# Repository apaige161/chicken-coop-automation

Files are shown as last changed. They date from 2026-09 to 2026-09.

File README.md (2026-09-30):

# Automated 50-Bird Chicken Coop

This is a complete, buildable design for a **10 × 20 ft coop for 50 free-ranging hens**:
the structure, run and paddocks, water and power, plus an **ESP32 + ESPHome controller**
that integrates with **Home Assistant**. Every subsystem starts **low-tech**, and the
automation is an upgrade you can add later.

> ⚠️ **Safety and code.** This project includes **120 V mains wiring outdoors** and a
> **load-bearing structure**. The plans are detailed, but they are **not** a substitute for
> a **licensed electrician** (all 120 V work, GFCI protection, inspection) or for your
> **local building department** (permit, setbacks, snow/wind loads). The controller PCB
> itself carries only 12 V DC.

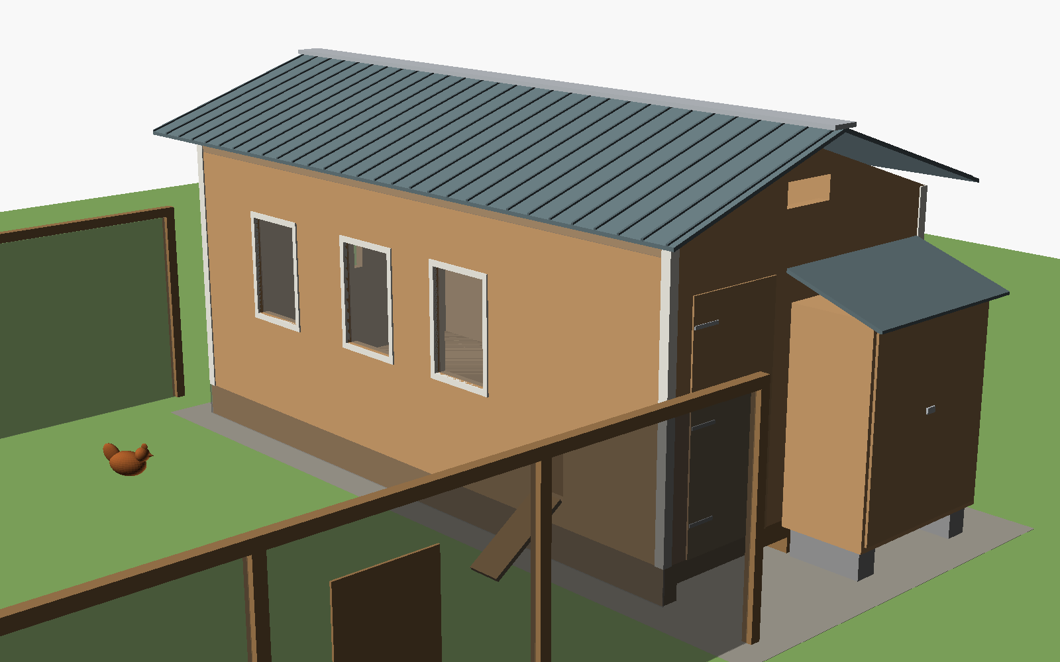
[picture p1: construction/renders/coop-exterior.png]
coop exterior


| Feed & water station (filled from outside) | Inside: roosts, nest openings, trough, drinkers |
|---|---|
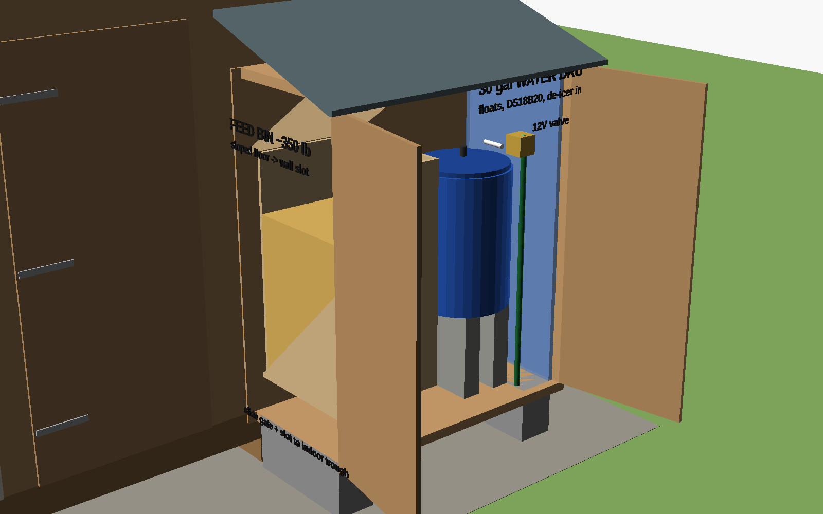
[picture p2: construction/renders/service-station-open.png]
service station
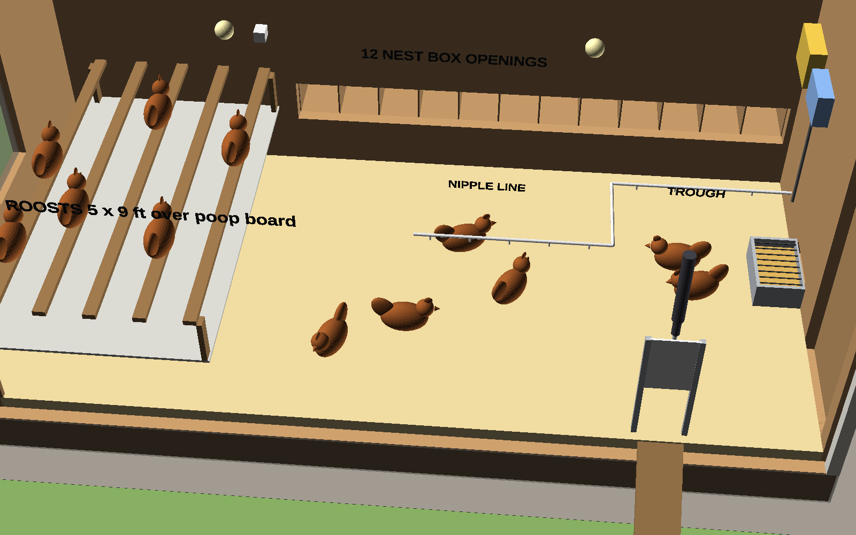
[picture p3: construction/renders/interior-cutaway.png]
interior
|  |  |
| **Nest bay (eggs collected from outside)** | **Controller PCB** |
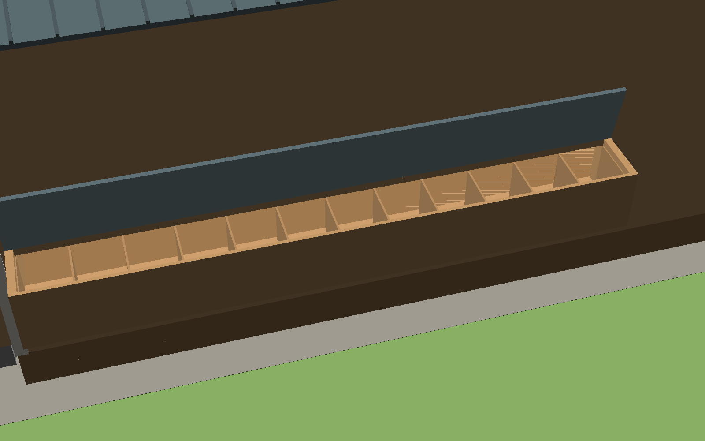
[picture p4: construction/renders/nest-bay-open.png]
nest bay
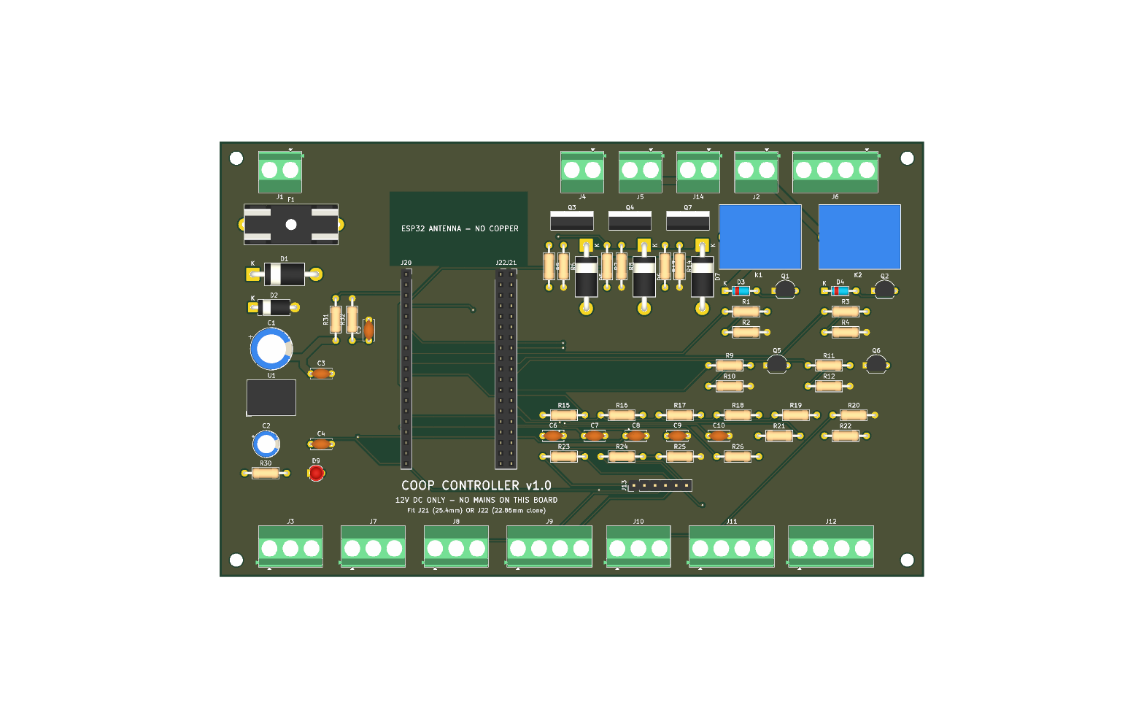
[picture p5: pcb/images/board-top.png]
pcb
|  |  |

The renders are illustrative OpenSCAD models (`construction/model/`). Dimensions come from
the build plan and drawings.

**Feed, water and eggs are all serviced from outside the coop.** An exterior service station
on the east wall holds a ~350 lb gravity feed bin (it feeds an indoor trough through a wall
slot) and the 30 gal water drum (piped through the wall to the nipple line). The nest bay
lid opens from outside.

## What's here

| Folder | Contents | Checked by |
|---|---|---|
| [`PROJECT_SPEC.md`](PROJECT_SPEC.md) | Architecture, sizing, tiers, power design, **GPIO map** | consistency check |
| [`hardware/pinmap.yaml`](hardware/pinmap.yaml) | Single source of truth for GPIOs and terminals | consistency check |
| [`firmware/`](firmware/) | ESPHome configs: controller + optional ESP32-CAM | `esphome config` + full compile |
| [`pcb/`](pcb/) | KiCad 10 schematic + 2-layer board, generated from `design.py`, autorouted, Gerbers ready to order | ERC 0 · DRC 0 errors · 0 unrouted · schematic parity |
| [`3d-printing/`](3d-printing/) | 8 OpenSCAD designs → 15 STLs (sensor housings, camera, brackets, PCB plate, optional auger funnel) | `render.sh` |
| [`construction/`](construction/) | Build plan + cut list, exterior feed/water station, wiring, plumbing, run and range, 5 diagrams, 6 renders | diagrams regenerate from `pinmap.yaml` |
| [`docs/`](docs/) | [Priced parts list](docs/parts-list.md), [cost-saving measures](docs/cost-savings.md), [Home Assistant setup](docs/home-assistant.md), HA automations + dashboard | `gen_parts_list.py --check`, yamllint |
| [`tools/`](tools/) | `check_consistency.py`, `gen_parts_list.py` | CI |

## Cost (2026 estimates, see [parts list](docs/parts-list.md))

| Tier | Approx. |
|---|---:|
| Tier 1: coop, run, electric-netting paddocks, exterior feed/water station, power to the coop | ~$9.6k |
| Tier 2: full automation (controller, PCB, door actuator, water fill, sensors) | ~$0.65k |
| Optional: camera, BLE sensors, battery backup, metered auger | ~$0.2k |

The cost-saving measures in [`docs/cost-savings.md`](docs/cost-savings.md) are already applied
(about −$950 net, *after* adding the exterior station). The biggest remaining levers are a
local lumber-package quote (±30 % on lumber) and how much of the ~$900 electrician estimate
you can reduce, for example by digging the trench yourself.

## Tiers at a glance

| Subsystem | Tier 1 (works with no electronics) | Tier 2 (controller) |
|---|---|---|
| Pop door | Guillotine door + rope/pulley | 12 V actuator, on-device sunrise/civil-dusk schedule, reed confirmation, HA alerts |
| Water | 30 gal drum in the exterior station, piped through the wall to nipples. Hose-fill from outside, or a mechanical float valve | Fail-closed solenoid, dual floats, timeout lockout, freeze-aware |
| Winter water | Insulated station + heated waterer on the GFCI outlet | DS18B20-controlled de-icer / heat cable via relay |
| Feed | ~350 lb gravity bin in the exterior station → wall slot → indoor trough, filled from outside | Ultrasonic bin level + low-feed alert. Optional metered auger |
| Light | Switch | Morning supplement to 14 h day length |
| Ventilation | Soffit/ridge/gable/windows (≥ 20 sq ft) | 12 V fan on temp/RH |
| Security | Hardware cloth, buried apron, 2-step latches, electric netting | PIR night-motion alerts, door-open-after-dark alert, optional camera |

## Build order

1. **Plan and permit.** Read `PROJECT_SPEC.md` and `construction/coop-build-plan.md`. Check
   local code, snow/wind loads and setbacks. Get a lumber quote from the cut list.
2. **Site, foundation, floor, walls, roof** (`coop-build-plan.md` §2 steps 1–9).
3. **Predator proofing and openings.** Hardware cloth everywhere, apron, doors, windows,
   nest bay, roosts.
4. **Run and paddocks** (`run-and-fencing.md`).
5. **Exterior feed & water station** (`coop-build-plan.md` §7): gravity feed bin + indoor
   trough, drum + drinker line through the wall, supply chain (`plumbing.md`).
   **Birds can move in now.** Keep them in the run for 1–2 weeks so they learn the coop is home.
6. **Power** (`wiring.md`). The electrician installs the feeder, mains box, lights and GFCI
   receptacle.
7. **Controller:** order the PCB (`pcb/fab/coop-controller-gerbers.zip`), print the parts
   (`3d-printing/stl/`), buy the Tier 2 parts, assemble and bring up the board
   (`pcb/README.md`), flash the firmware and adopt it in HA (`docs/home-assistant.md`).
8. **Commission one subsystem at a time:** door (adjust the reeds, watch a dusk close),
   then water fill, de-icer, feed-level sensor, lights, fan. Import the HA automations and
   dashboard.
9. **Optional:** camera, BLE thermometers, battery backup.

## Verify everything (what CI runs)

```bash
python tools/check_consistency.py      # pin map ↔ firmware ↔ PCB ↔ spec ↔ HA entity IDs ↔ schematic
python tools/gen_parts_list.py --check  # parts list totals are current
python construction/gen_diagrams.py     # diagrams regenerate
esphome config firmware/coop-controller.yaml
bash 3d-printing/render.sh
bash pcb/build.sh                       # needs KiCad 10 + Java + Freerouting: ERC/DRC/fab outputs
```

## Before building: check these by hand

These are the things software checks can't prove:

- [ ] **PCB:** open it in KiCad and review the autorouted layout. Confirm the SRD relay
      pinout on your parts, and your ESP32 board's row spacing (fit J21 for 25.4 mm or
      J22 for 22.86 mm). See `pcb/README.md`.
- [ ] **Firmware:** set your latitude/longitude/timezone and feeding times, and your BLE
      thermometer's MAC (or remove `packages/ble.yaml`).
- [ ] **3D parts:** measure your specific sensors and PVC and adjust the parameters in the `.scad` headers.
- [ ] **Structure:** check rafter size against your local snow load, and pull a permit if needed.
- [ ] **Electrical:** a licensed electrician does all 120 V work, with GFCI on everything.

## Design decisions

- **ESPHome** rather than Arduino/ESP-IDF: it's local-first, integrates natively with
  HA, and each entity is a few lines of YAML, which keeps the upgrade path cheap.
- **KiCad** rather than Eagle: it's free, it's scriptable (the board is generated and
  verified from `pcb/design.py`), and it outputs standard Gerbers for any fab.
- **Mains stays off the PCB.** The relay modules (or SSRs) and PSU sit in a separate
  electrician-installed box. The PCB only drives their 12 V coils/inputs.
- **Service from outside.** Feed, water and egg collection never require entering the coop,
  which cuts labour, spills and biosecurity risk.

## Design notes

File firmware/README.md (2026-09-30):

# Firmware (ESPHome)

| File | Device |
|---|---|
| `coop-controller.yaml` | Main controller: ESP32-DevKitC-32E on the Coop Controller PCB |
| `packages/base.yaml` | WiFi/AP fallback, API (encrypted), OTA, web UI, SNTP/HA time, sun, status LED, 12 V monitor |
| `packages/door.yaml` | Pop door: relay H-bridge, reed end stops, sun-elevation schedule with a lux fallback, fault alerts |
| `packages/water.yaml` | Float-controlled fill with timeout lockout + valve watchdog, DS18B20, de-icer thermostat |
| `packages/feeder.yaml` | Feed-bin level (JSN-SR04T) + low-feed alert. Optional metered auger (schedule off by default) with door/auger power interlock |
| `packages/lighting_fan.yaml` | Morning light supplement to the target day length, temp/RH exhaust fan |
| `packages/environment.yaml` | BME280 + BH1750 on I2C |
| `packages/security.yaml` | PIR + "night motion" |
| `packages/ble.yaml` | BLE tracker + HA Bluetooth proxy + pvvx thermometer example |
| `coop-camera.yaml` | Optional AI-Thinker ESP32-CAM |

GPIO numbers **must** match `hardware/pinmap.yaml`. Each `GPIOxx` line carries a
`# SIGNAL_NAME` comment, which `tools/check_consistency.py` verifies.

## Design rules

- **Local first.** Nothing the birds depend on needs HA or internet. `reboot_timeout: 0s`
  on the API and WiFi means the controller never reboots just because HA or WiFi is gone.
- **Fail safe.** All outputs are `ALWAYS_OFF` at boot, with gate pull-downs on the PCB.
  The door relays interlock in software, and the relay topology makes shoot-through
  impossible anyway. The valve closes on timeout and has its own watchdog. The optional auger
  has a 150 s cap. The float wiring convention makes a broken wire read as "don't fill".
- **Manual overrides stick** until the next scheduled transition, because the door and
  light schedulers only act on *changes* in the desired state.
- **Everything tunable is a `number`/`switch` entity** (restored across reboots), so
  thresholds change from HA or the web UI without reflashing.

## Build / flash

```bash
pip install esphome
cp secrets.example.yaml secrets.yaml      # then edit it
esphome config coop-controller.yaml       # validate
esphome run coop-controller.yaml          # compile + flash (USB first time, then OTA)
```

Verified with ESPHome 2026.9.0 (esp-idf 5.5.5): the controller uses 61 % RAM / 75 % flash,
the camera 32 % RAM / 54 % flash.

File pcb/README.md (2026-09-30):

# Coop Controller PCB (KiCad)

This is a 2-layer, all through-hole carrier board for an **ESP32-DevKitC-32E**. It has 12 V
input protection, a 5 V regulator, a 2-relay H-bridge for the pop-door actuator, five
low-side MOSFET outputs, conditioned sensor inputs, and screw terminals for all field
wiring. **It carries 12 V DC only.** The 120 V relays/SSRs and PSU live in a separate mains
enclosure (see `construction/wiring.md`).

top

| | |
|---|---|
| Size | 170 × 105 mm, 4× M3 holes 4 mm from each corner |
| Layers | 2 (1 oz), GND pour both sides, solid pad connections |
| Tracks | Signal 0.25 mm / 0.2 mm clearance. Power nets (`+12V`, `GND`, `M±`, `VALVE-`, `FEEDER-`, `FAN-`, `VIN_*`) 1.5 mm |
| Parts | 75 THT parts, 38 BOM lines (`fab/bom.csv`) |
| Checks | ERC 0 violations. DRC 0 errors, 0 unconnected, 0 schematic-parity issues |

## Files

| File | What it is |
|---|---|
| `design.py` | **The source.** Every part, footprint, pin→net and board position |
| `gen_schematic.py` | Writes `coop-controller.kicad_sch` from `design.py` (labels on every pin) |
| `gen_pcb.py` | Writes `coop-controller.kicad_pcb` + `.kicad_pro` (placement, net classes, outline, keep-out, pours) |
| `route.py` | Autoroutes with Freerouting (retries until 100% routed) and fills the pours |
| `gen_bom.py` | Grouped BOM → `fab/bom.csv` |
| `build.sh` | Runs everything above, plus ERC/DRC and fab exports |
| `fab/coop-controller-gerbers.zip` | **Upload this to the fab** (Gerbers + Excellon drill) |
| `fab/coop-controller-schematic.pdf` | Printable schematic |

The schematic is generated, so it's a netlist-style sheet grouped by function, with net
labels instead of drawn wires. That's deliberate: `tools/check_consistency.py` can prove it
matches `design.py` and the firmware pin map. To change the circuit, edit `design.py` and
run `bash build.sh`. Don't hand-edit the generated files, or the next build will overwrite
your changes.

## Before you order: manual checks

The layout is autorouted and passes DRC, but nobody has looked at it in the KiCad GUI yet.
Open `coop-controller.kicad_pcb` in KiCad and check:

1. **Relay pinout.** `design.py` assumes SRD pins 1 = COM, 2/5 = coil, 3 = NO, 4 = NC
   (KiCad's `SANYOU_SRD_Form_C` symbol). Confirm this on your actual relays with a
   meter before soldering.
2. **ESP32 fit.** Measure your dev board. Official Espressif DevKitC rows are 25.4 mm apart
   (fit **J21**). Many clones are 22.86 mm (fit **J22** instead). Fit only one of the two.
   Make sure the USB connector sits at the bottom (J20/J21 pin 19 end) and the antenna
   overhangs the "NO COPPER" keep-out.
3. **Terminal-block orientation.** Wire entries should face the board edges.
4. **Track routing.** Look over the Freerouting result: power-track widths, sensible
   paths, no long GND detours.
5. Run **Inspect → Design Rules Checker** once in the GUI.

## Ordering (JLCPCB / PCBWay / OSH Park)

1. Upload `fab/coop-controller-gerbers.zip`.
2. Settings: 2 layers, 1.6 mm FR-4, 1 oz copper, HASL (lead-free) or ENIG, any mask colour.
   Minimum track/space on this board is 0.25/0.2 mm, which every hobby fab handles.
3. Expect roughly **$15–30 for 5 boards** plus shipping, since it's over 100×100 mm.
4. The parts are all through-hole and commonly stocked, so hand-solder them from
   `fab/bom.csv` (Digi-Key/Mouser/LCSC). Prices are in `docs/parts-list.md`.

## Assembly order

Solder low to high: resistors, diodes, small caps, TO-92 transistors, then the pin
header/sockets (use a spare dev board to hold the sockets straight), TO-220 MOSFETs,
electrolytics, fuse holder, regulator, relays and terminal blocks last.

**Bring-up before plugging in the ESP32:**
1. Apply 12 V from a current-limited bench supply (limit to about 200 mA). Check that
   D9 lights, 5 V is on J10 pin 1, and nothing gets warm.
2. Check reverse polarity: swap the leads briefly. Nothing should happen, because D1
   blocks it.
3. Fit the ESP32, flash `firmware/coop-controller.yaml` over USB, then test each output
   from the ESPHome web UI with nothing connected. Listen for the relay clicks and check
   that the MOSFET drains pull low.

## Circuit notes

- **Door H-bridge:** K1/K2 SPDT. NC→GND, NO→+12 V, COM→motor lead. Both relays off (or
  both on) shorts the motor to itself, which brakes it. Shoot-through is impossible by
  construction. See the truth table in `PROJECT_SPEC.md`.
- **Low-side outputs:** IRLZ44N (or IRLB8721) logic-level FETs with 100 Ω gate and 100 kΩ
  pull-down resistors, so outputs stay OFF while the ESP32 boots. 1N5822 flyback diodes
  protect against the valve/motor/fan inductance. 2N7000 FETs drive the relay coils (1N4148
  flyback) and the J6 outputs for the mains-box relay-module coils (~20 mA; use modules with
  a built-in suppression diode) or SSR inputs (~10 mA). J5 (FEEDER) is only used by the
  optional metered auger.
- **Inputs:** 10 kΩ pull-ups to 3.3 V plus a 100 nF cap on every long-wire input. The PIR
  has a 10 kΩ pull-down. The JSN-SR04T 5 V echo goes through a 1 k/2 k divider.
- **VIN sense:** 100 k/22 k divider into GPIO36. The firmware multiplies by 5.545.
- **Protection:** 5 A slow-blow fuse, SB560 series Schottky (reverse polarity), and a
  P6KE15CA TVS across +12 V.

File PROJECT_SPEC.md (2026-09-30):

# Project Spec: Automated 50-Bird Chicken Coop

This is the shared architecture document. Firmware, PCB, wiring diagrams, 3D parts and
construction plans all follow it. If you change it, change it here first, then update
`hardware/pinmap.yaml` and run `python tools/check_consistency.py`.

> **SAFETY — READ FIRST.** This project includes 120 V AC mains wiring outdoors and a
> load-bearing structure for 50 birds plus snow and wind loads. These plans are thorough,
> but they do **not** replace a licensed electrician or a local building/code review.
> All outdoor 120 V circuits must be **GFCI protected** and installed to local code
> (NEC in the US). Have the electrical work inspected and the structure checked against
> your local snow/wind loads before you build.

## 1. Design philosophy

Every subsystem has a **Tier 1 (low-tech)** baseline that works with no electronics at all,
and a **Tier 2 (automated)** upgrade that the controller adds on top. The flock stays safe
if the controller, WiFi or Home Assistant fails:

- The pop door runs from **local sunrise/sunset logic on the ESP32**. It does not need Home
  Assistant or internet, and a physical button on the enclosure works without WiFi.
- A mechanical float valve or a manual fill still waters the birds if the solenoid fails.
- Feed and water are gravity-fed from an **exterior service station**, so a failed controller
  never stops the birds eating or drinking.

## 2. Site assumptions

| Item | Value |
|---|---|
| Flock | 50 standard-size laying hens, free-ranging most of the day |
| Shade | Partial. Put the long glazed wall facing south (north hemisphere) for winter sun, with deciduous shade in summer if you can |
| Power | 120 V outlet nearby. Run a dedicated GFCI-protected 20 A circuit to the coop |
| Water | Hose spigot nearby. Use a vacuum breaker, 25 psi regulator and a drinking-water-safe hose |

## 3. Coop sizing (50 birds)

| Parameter | Rule of thumb | Design value |
|---|---|---|
| Indoor floor area | 4 sq ft/bird | **10 ft × 20 ft = 200 sq ft** |
| Nest boxes | 1 per 4–5 hens | **12 boxes** in one row (12"W × 12"H × 14"D), exterior bay on the north wall, floor 20" up, so all boxes sit below the 36–40" roosts |
| Roost length | 8–10 in/bird | **5 bars × 9 ft = 45 ft** (10.8 in/bird), spanning the 9'-5" interior width |
| Ventilation | ~1 sq ft per 10 sq ft floor | **≥20 sq ft** of screened soffit, gable and window openings |
| Pop door | 1 per ~50 birds | **12" W × 16" H**, vertical guillotine, 12 V 18"-stroke actuator |
| Secure run (bad-weather days) | ~10 sq ft/bird | **20 ft × 25 ft = 500 sq ft**, roofed or netted |
| Feed | ~0.25 lb/bird/day | **~12.5 lb/day** (~90 lb/week) |
| Water | ~0.12–0.25 gal/bird/day | **6–12 gal/day**. A 30 gal reservoir lasts 2.5–5 days |
| Feed + water access | Fill without entering the coop | **Exterior service station** on the east wall (5 ft × 30 in × 6 ft): ~350 lb gravity feed bin + 30 gal drum, both filled from outside |

## 4. System architecture

```
                      +-------------------- Home Assistant ---------------------+
                      |  dashboards, overrides, notifications, history          |
                      +--------------------------+------------------------------+
                                                 | ESPHome native API (WiFi, encrypted)
          BLE (passive)                          |
 [BLE thermometer(s)] ~~~~~~~~~~~~~~>  +---------+-----------+      optional     +-------------+
 (nest box / brooder)                  |  Coop Controller    |  <--- WiFi ---->  | ESP32-CAM   |
                                       |  ESP32-DevKitC-32E  |                   | (camera)    |
                                       |  on Coop Ctrl PCB   |                   +-------------+
                                       +--+--+--+--+--+--+--+
     12 V DC loads:  door actuator (2-relay H-bridge), water solenoid, 12 V fan, (optional feed auger)
     Low-voltage in: door reeds, water floats, DS18B20, BME280, BH1750, PIR, ultrasonic, button
     Relay/SSR out:  relay 1 -> 120 V coop lights, relay 2 -> 120 V de-icer (mains stays OFF the PCB)
```

- **Firmware:** ESPHome (YAML). It is local-first and integrates natively with Home Assistant.
  The coop logic (door schedule, water fill, freeze protection, lighting, feeding) runs on
  the device. Home Assistant supervises and can override.
- **BLE:** The controller runs `esp32_ble_tracker` passively to read BLE thermometers such
  as the Xiaomi LYWSD03MMC with pvvx firmware in the nest boxes or brooder. It also works
  as a Home Assistant **Bluetooth proxy**, so more BLE sensors can be added later without
  new hardware.
- **Camera (optional):** A separate ESP32-CAM node running ESPHome, or any RTSP/ONVIF
  camera added to Home Assistant directly.

## 5. Power architecture

```
House panel --[20 A GFCI breaker]-- UF-B 12/2 (buried per code) --> Coop weatherproof mains box
   Mains box (NEMA 4X / IP65), DIN rail:
     - 2-pole disconnect / 20 A breaker
     - GFCI receptacle (if not GFCI at panel)
     - Mean Well HDR-100-12N (12 V 7.5 A DIN PSU) ---> 12 V to controller box
     - Relay 1: DIN relay module, 12 VDC coil, 6 A (or SSR) -> coop LED lights
     - Relay 2: same                                       -> water de-icer / heat cable (<= 500 W)
   Optional: 12 V 7 Ah SLA battery + float charger for door backup during power cuts
```

- The **controller PCB carries 12 V DC and below only.** It switches the relay coils (or SSR
  inputs) on the low side. The relays, PSU and all 120 V conductors live in a separate
  mains enclosure. Use relay modules with a built-in suppression diode.
- 12 V input: 5 A fuse → reverse-polarity Schottky → TVS → loads. 5 V comes from an
  onboard switching regulator (7805-footprint module). The ESP32 dev board takes 5 V on
  its `5V` pin and makes 3.3 V itself.

## 6. Controller GPIO map (single source of truth: `hardware/pinmap.yaml`)

Board: **ESP32-DevKitC-32E** (38-pin, ESP32-WROOM-32E). Strapping pins (0, 2, 5, 12, 15)
are avoided or used only in boot-safe ways. GPIO 34/35/36/39 are input-only and have no
internal pull-ups, so the PCB provides external 10 kΩ pull-ups.

| GPIO | Signal | Dir | Connector | Notes |
|---|---|---|---|---|
| 21 | I2C_SDA | I/O | J9 | BME280 (0x76), BH1750 (0x23). 4.7 kΩ pull-ups on PCB |
| 22 | I2C_SCL | O | J9 | |
| 4 | ONEWIRE | I/O | J8 | DS18B20 in the water reservoir. 4.7 kΩ pull-up |
| 25 | DOOR_OPEN_RLY | O | J2 (via K1) | Relay K1: actuator M+ to +12 V (extend = open) |
| 26 | DOOR_CLOSE_RLY | O | J2 (via K2) | Relay K2: actuator M− to +12 V (retract = close) |
| 32 | DOOR_CLOSED_SW | I | J3 | Reed switch to GND, pulled up |
| 33 | DOOR_OPEN_SW | I | J3 | Reed switch to GND, pulled up |
| 27 | VALVE_DRV | O | J4 | Low-side MOSFET, 12 V NC solenoid valve |
| 13 | FEEDER_DRV | O | J5 | Low-side MOSFET, optional 12 V metered-auger motor |
| 14 | FAN_DRV | O | J14 | Low-side MOSFET, 12 V exhaust fan (may blip at boot; harmless) |
| 16 | LIGHT_SSR | O | J6 | Low-side MOSFET → relay 1 coil / SSR1 input (120 V lights) |
| 17 | HEAT_SSR | O | J6 | Low-side MOSFET → relay 2 coil / SSR2 input (120 V de-icer) |
| 34 | WATER_LOW | I | J7 | Float switch to GND, ext. 10 kΩ pull-up, RC filter |
| 35 | WATER_HIGH | I | J7 | Float switch to GND, ext. 10 kΩ pull-up, RC filter |
| 39 | PIR | I | J10 | HC-SR501 output (3.3 V logic), 10 kΩ pull-down |
| 18 | US_TRIG | O | J11 | JSN-SR04T feed-bin level ultrasonic trigger |
| 19 | US_ECHO | I | J11 | 5 V echo through a 1 kΩ/2 kΩ divider |
| 23 | DOOR_BTN | I | J12 | Panel push button to GND (manual door toggle) |
| 2 | STATUS_LED | O | J12 | Onboard LED + panel LED (330 Ω) |
| 36 | VIN_SENSE | ADC | — | 12 V rail through 100 kΩ/22 kΩ divider (battery/PSU health) |
| 5 | SPARE_IO5 | I/O | J13 | Expansion header. Strapping pin: do not pull low at boot |

**Door H-bridge truth table** (K1/K2 are SPDT; NC→GND, NO→+12 V, COM→motor lead):

| K1 | K2 | M+ | M− | Result |
|---|---|---|---|---|
| off | off | GND | GND | Stopped (dynamic brake) |
| on | off | +12 V | GND | Extend → **door opens** |
| off | on | GND | +12 V | Retract → **door closes** |
| on | on | +12 V | +12 V | Stopped (no shoot-through possible) |

The firmware still interlocks K1/K2. The actuator's built-in limit switches are the
primary end stop. The reed switches and a 30 s runtime timeout are secondary.

## 7. Subsystems

| Subsystem | Tier 1 (low-tech) | Tier 2 (automated) |
|---|---|---|
| Pop door | Manual guillotine door + rope/pulley and latch | 12 V linear actuator, sunrise/sunset + lux logic on-device, reed confirmation, HA alert if not closed 30 min after sunset |
| Feeder | ~350 lb gravity bin in the exterior station, feeding an indoor trough through a wall slot, filled from outside | Ultrasonic feed-level sensor + low-feed alert. Optional metered auger on J5 for rationing |
| Water | 30 gal drum in the exterior station, piped through the wall to nipples/cups, hose-filled from outside | 12 V NC solenoid from spigot, low/high float fill control with max-runtime and leak lockout |
| Freeze protection | Insulated station + heated bucket by hand | DS18B20 water temp → relay 2 de-icer/heat cable, HA freeze alerts |
| Lighting | Manual switch | Relay 1 adds morning light to keep 14 h of daylight in winter |
| Ventilation | Screened soffit/gable/window openings | 12 V exhaust fan on temperature/humidity thresholds |
| Environment | Min/max thermometer | BME280 (T/RH/P), BH1750 lux, BLE thermometers, HA history |
| Security | Hardware cloth, buried apron, latches | Door reeds, PIR night alerts, optional camera, electric poultry netting for range area |

## 8. Repository layout

| Path | Contents |
|---|---|
| `hardware/pinmap.yaml` | GPIO/connector source of truth |
| `firmware/` | ESPHome configs: `coop-controller.yaml`, `coop-camera.yaml`, packages |
| `pcb/` | KiCad project (generated by `pcb/generate.py`), BOM, fab notes, Gerbers |
| `3d-printing/` | OpenSCAD sources + print/service notes |
| `construction/` | Coop build plan, cut list, wiring and plumbing diagrams, run/fencing plan |
| `docs/` | Parts list and price breakdown, Home Assistant setup, build order |
| `tools/` | Consistency checks, BOM tooling |

## 9. Verification gates

Each step is committed only after its checks pass:

1. `esphome config` passes for every firmware YAML.
2. `python tools/check_consistency.py` passes: the pin map matches the firmware, PCB netlist and docs.
3. KiCad ERC/DRC via `kicad-cli` runs clean, with only documented waivers.
4. OpenSCAD renders every part to STL without errors.
5. The BOM totals regenerate from CSV without diffs.

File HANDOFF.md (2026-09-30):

# Handoff / Status

**Status: complete (design package v1.0).** The original goals in the first session's
handoff are all implemented and verified. See `README.md` for the build order and the
"Before building: check these by hand" list.

## Done
- Spec + single-source pin map (`PROJECT_SPEC.md`, `hardware/pinmap.yaml`)
- ESPHome firmware: controller + optional camera. Validated and compiled (ESPHome 2026.9)
- KiCad PCB generated from `pcb/design.py`, autorouted (Freerouting). ERC/DRC clean, Gerbers + BOM
- 8 OpenSCAD parts → 15 STLs
- Construction plan, cut list, wiring/plumbing/run docs, 5 generated diagrams
- Priced parts list (2026 estimates), Home Assistant docs/automations/dashboard
- `tools/check_consistency.py` + GitHub Actions CI
- v1.1: feed and water serviced from OUTSIDE via an exterior service station (gravity feed bin +
  drum), 6 OpenSCAD renders (`construction/renders/`), cost-saving measures applied
  (`docs/cost-savings.md`, about -$950 net). Repo made public.

## Decisions that stand (the user can redirect)
- ESPHome instead of raw Arduino/ESP-IDF, KiCad instead of Eagle.
- Mains stays off the PCB (separate electrician-installed mains box with SSRs + PSU).

## Needs a human
- Review the autorouted PCB in the KiCad GUI before ordering. Confirm the relay pinout and
  the ESP32 row spacing.
- Electrician for all 120 V work. Local permit and snow/wind-load check for the structure.
- Site-specific firmware substitutions (lat/long/timezone, feeding times, BLE MAC).

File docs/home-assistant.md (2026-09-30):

# Home Assistant Setup

The coop controller is an **ESPHome** device. Home Assistant finds it automatically and
gets full control of it. The coop never *depends* on HA, though: all the scheduling and
safety logic runs on the ESP32.

## 1. Flash the firmware

1. Install ESPHome: the ESPHome Device Builder add-on in HA, or
   `pip install esphome` on a PC.
2. Copy `firmware/secrets.example.yaml` to `firmware/secrets.yaml` and fill in your WiFi
   details. Generate the two API keys with the one-liner in the file.
3. Edit the `substitutions:` at the top of `firmware/coop-controller.yaml`: **latitude,
   longitude, timezone** (these drive the sunrise/sunset door and lights), the feeding
   hours (only used with the optional auger), and the feed-bin depth for the level sensor.
4. The first flash goes over USB: `esphome run firmware/coop-controller.yaml`. After that,
   updates go over WiFi (OTA, encrypted with the API key).
5. **Windows users:** if compiling fails with `c++config.h` / path-length errors, set
   `ESPHOME_ESP_IDF_PREFIX=C:\esphidf` and run from PowerShell or cmd, not Git Bash.

If WiFi isn't configured or is out of range, the device starts a setup access point
called **Coop-Controller-Setup** (captive portal). Its local web UI
(`http://coop-controller.local`, user `admin`) controls everything without HA.

## 2. Add it to Home Assistant

Go to Settings → Devices & services. The **ESPHome: Coop** device should appear as
"Discovered". Click **Configure** and paste the `api_encryption_key`.

## 3. Entities

| Entity | What it does |
|---|---|
| `cover.coop_pop_door` | Open/close/stop the pop door (endstop cover with reed-switch feedback) |
| `switch.coop_door_auto_mode` | On-device sunrise/sunset schedule. Turn it off for a manual day |
| `number.coop_door_open_sun_elevation` / `…_close_sun_elevation` | Open when the sun is ≥ +2°, close at ≤ −6° (civil dusk) |
| `number.coop_door_earliest_open` | Don't open before this hour (default 06:30), to keep predators at dawn out |
| `switch.coop_water_auto_fill`, `button.coop_water_fill_now`, `button.coop_water_fill_lockout_reset` | Water fill control |
| `number.coop_water_max_fill_time` | Fill timeout before lockout (default 10 min) |
| `switch.coop_water_de_icer`, `switch.coop_de_icer_auto`, `number.coop_de_icer_on_below` / `…_off_above` | Freeze protection (3 °C on / 6 °C off) |
| `sensor.coop_feed_level`, `binary_sensor.coop_feed_low` | Level of the exterior gravity feed bin (ultrasonic in the lid) |
| `switch.coop_feeder_auto_schedule`, `button.coop_dispense_feed_now`, `number.coop_feeder_run_time` | **Optional metered auger only** (off by default). Twice daily at 07:00/15:00 when enabled |
| `switch.coop_coop_light`, `switch.coop_light_auto_winter_supplement`, `number.coop_target_day_length` | Morning light supplement up to 14 h of daylight |
| `switch.coop_exhaust_fan`, `switch.coop_fan_auto`, `number.coop_fan_on_above` | Ventilation fan |
| `sensor.coop_coop_temperature` / `_humidity` / `_pressure`, `sensor.coop_outdoor_light`, `sensor.coop_water_temperature`, `sensor.coop_feed_level` | Telemetry |
| `binary_sensor.coop_door_fault`, `…_door_open_after_dark`, `…_water_fill_lockout`, `…_water_float_fault`, `…_water_freeze_risk`, `…_feed_low`, `…_12v_supply_low`, `…_night_motion` | Problems. Hook these to notifications |
| `sensor.coop_nest_box_temperature` (BLE) | From the pvvx BLE thermometer, if fitted |

The controller also acts as a **Bluetooth proxy**, so other BLE devices near the coop
(BTHome door/gate sensors, more thermometers) appear in HA without any firmware changes.

## 4. Automations and dashboard

- `docs/ha/automations.yaml` has a problem alert (any fault sensor → phone push), a
  night-motion alert, a controller-offline alert, an evening "door didn't close" check,
  and an auto-mode re-enable at 03:00.
- `docs/ha/dashboard.yaml` is a ready-made dashboard (door tile, status glance, gauges,
  48 h climate graph, controls). Paste it into a new dashboard's raw config editor.

Replace `notify.notify` with your phone's notifier (`notify.mobile_app_<name>`).

## 5. Camera (optional)

- **ESP32-CAM:** flash `firmware/coop-camera.yaml` (board `esp32cam`). It appears as
  `camera.coop_camera_…`, and you can add a `picture-entity` card.
- **Better option:** an outdoor PoE or WiFi camera with IR and RTSP/ONVIF (Reolink, Amcrest
  and similar) through HA's ONVIF / Generic Camera integration. Frigate NVR can add
  person/animal detection later.

## 6. Upgrade path

| Now | Later |
|---|---|
| On-device schedule | HA automations for vacation mode, egg-count logging, weather-aware door times |
| 1 PIR | Camera + Frigate object detection (fox, raccoon, hawk) |
| Manual range gates | Second actuator on expansion header IO5 (J13) for a run → paddock gate |
| BME280 | Ammonia sensor (e.g. MQ-137 via ADS1115 on the J13 I2C) for litter management |
| Mains only | Battery backup (see `construction/wiring.md`), later solar |

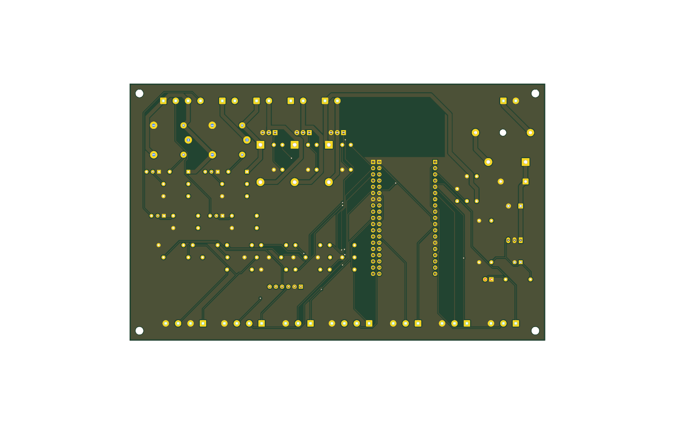
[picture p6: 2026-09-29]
pcb/images/board-bottom.png

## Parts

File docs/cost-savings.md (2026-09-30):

# Cost-Saving Measures

The rule for this list: **cheaper without adding real complexity or weakening the flock's
safety.** Section 1 is already applied to `docs/parts.csv`, so the totals in
[`parts-list.md`](parts-list.md) include it. Section 2 lists optional savings that depend
on your situation. Section 3 covers cuts that look tempting but aren't worth it.

**Net effect of section 1:** the recommended build (Tier 1 + Tier 2) went from about
**$11,190 to $10,240 (−$950)**. That's after also *adding* the ~$350 exterior feed/water
service station, which makes feed and water accessible from outside the coop.

## 1. Applied (in the parts list)

| # | Change | Saves | Why it doesn't add complexity |
|---|---|---:|---|
| 1 | **One electric-netting roll, moved between paddocks** instead of three standing rolls | ~$430 | Moving a 164 ft roll takes about 15 min every 2–4 weeks. Buy more rolls later if you want |
| 2 | **Shade sail over half the run** instead of a steel-roofed section | ~$410 | The coop is the rain shelter; the run only needs summer shade. The sail comes down for winter along with the netting |
| 3 | **Porch & floor enamel** on the PT plywood instead of sheet vinyl | ~$125 | Roll on two coats once the plywood has dried out. Just as easy to scrape under deep litter |
| 4 | **Gravel strips under the skids** instead of a full 12 × 22 ft gravel pad | ~$110 | Less digging too. The hardware-cloth skirt and apron do the rodent-proofing |
| 5 | **DIN relay modules** (12 V coil, built-in diode) instead of genuine SSRs for lights and de-icer | ~$75 | The same J6 outputs drive them, and they can't be counterfeit-shorted. SSRs stay a documented alternative |
| 6 | **Gravity feed bin + indoor trough** instead of hanging feeders + a motorized auger/hopper | ~$65 | *Fewer* parts: no motor, auger, coupler or hopper can. Feed flows as the hens eat. The auger is now an optional add-on for rationing |
| 7 | **Storm shutters from the window cut-outs** instead of polycarbonate winter panels | ~$65 | The T1-11 from the window openings becomes the shutters. Only hinges and hooks to buy |
| 8 | **Used food-grade drum** (car washes, bakeries, farm stores) instead of new | ~$25 | Rinse it well. Only buy drums that held food-grade contents |
| | *Added:* exterior feed & water service station | −$350 | The requested outside access: framing, siding, a small roof, foam, hinges and latches |

## 2. Optional: depends on your situation

| Idea | Typical saving | Notes |
|---|---:|---|
| **Get a lumber-package quote from a local yard** from the cut list in `construction/coop-build-plan.md` | 10–15 % of ~$4.5k lumber ≈ $450–650 | Local yards often beat big-box prices on full packages and deliver for free |
| **Dig the feeder-cable trench yourself.** The electrician only does terminations, the mains box and the inspection | $200–400 of the $900 labour estimate | Ask your electrician first; many are happy to do this. Call 811 before digging |
| **Reclaimed metal roofing or siding** | $300–900 | Check it for rust-through and sharp edges. Only fine if it's sound |
| **Skip the exhaust fan** (J14) in mild climates | ~$32 | The soffit + ridge + window ventilation (≥ 20 sq ft) is enough on its own in most climates |
| **ESP32 clone board** instead of the official DevKitC | ~$5 | The PCB has the J22 socket row for 22.86 mm clones |
| **Stage Tier 2.** Build Tier 1 now and add the controller in a later season | Spreads ~$650 | Every Tier 1 part stays in use when Tier 2 is added |
| **Skip the camera and BLE sensors** | ~$90 | Purely optional |

## 3. Not recommended (false economies)

- **Chicken wire instead of ½" hardware cloth.** Raccoons tear it and weasels pass through.
  One predator night costs more than the whole mesh budget.
- **Skipping the GFCI or the electrician** on the 120 V side. That's a safety and code issue.
- **Lighter rafters, or no rafter ties.** Structural. Check against your snow load.
- **Cheap no-name SSRs** (counterfeit "Fotek"). They fail shorted. Use genuine SSRs or the
  relay modules.
- **Garden hose for drinking water.** It leaches lead/BPA. The drinking-water hose is about $65.
- **PLA for outdoor printed parts.** It warps in a hot coop within a season. PETG costs about the same.

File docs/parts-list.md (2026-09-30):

# Parts List and Price Breakdown

> Generated from `docs/parts.csv` by `tools/gen_parts_list.py`. Edit the CSV, not this file.
> Prices are **2026 USD estimates** (big-box lumber yard / Digi-Key / Amazon-class retail) and
> vary by region, and lumber by ±30 %. Get a local lumber quote from the cut list in
> `construction/coop-build-plan.md`. Tools, tax and delivery are not included.

## Summary

| Tier | Total |
|---|---:|
| Tier 1: coop, run, low-tech equipment and power to the coop | **$9,592** |
| Tier 2: automation (controller, door, water, feed, sensors) | **$645** |
| Optional add-ons (camera, BLE sensors, battery backup, metered auger) | **$214** |
| **Tier 1 + Tier 2 (recommended build)** | **$10,237** |
| Everything | $10,451 |

Where the money goes: floor, wall and roof framing, siding and steel are 44% of Tier 1, and the run plus electric-netting paddocks another 13%. The whole automation tier adds only 7% on top of Tier 1.

## Tier 1: coop, run, low-tech equipment and power to the coop

### Site & foundation: $342

| Item | Spec | Qty | Unit | Total | Notes |
|---|---|---:|---:|---:|---|
| Crushed stone | 3/4 in. clean crushed stone (cu yd) | 1.5 | $55.00 | $82 | 3 x 12 in. gravel strips under the skids + service-station base (full pad optional) |
| Landscape fabric | 4 ft x 100 ft woven | 1 | $35.00 | $35 |  |
| Skids | 4x6x20 PT ground-contact | 3 | $75.00 | $225 |  |

### Floor: $933

| Item | Spec | Qty | Unit | Total | Notes |
|---|---|---:|---:|---:|---|
| Rim joists | 2x6x20 PT | 2 | $34.00 | $68 |  |
| Floor joists | 2x6x10 PT | 16 | $14.00 | $224 | 16 in. o.c. |
| Joist hangers | 2x6 face-mount (Simpson LUS26 or eq.) | 28 | $1.60 | $45 |  |
| Hurricane ties | H2.5A or eq. | 72 | $0.90 | $65 | joists-to-skids + rafters-to-plates |
| Subfloor | 3/4 in. PT plywood 4x8 | 7 | $68.00 | $476 |  |
| Floor paint | porch & floor enamel 1 gal (2 coats on the PT plywood) | 1 | $55.00 | $55 | replaces sheet vinyl |

### Walls: $1,993

| Item | Spec | Qty | Unit | Total | Notes |
|---|---|---:|---:|---:|---|
| Studs | 2x4x92-5/8 precut | 90 | $4.50 | $405 |  |
| Gable studs | 2x4x8 | 6 | $4.80 | $29 |  |
| Bottom plates | 2x4x10 PT | 7 | $8.50 | $60 |  |
| Top plates | 2x4x10 | 14 | $6.50 | $91 |  |
| Headers | 2x8x10 | 5 | $15.00 | $75 |  |
| Siding | T1-11 5/8 in. 4x9 panel | 17 | $72.00 | $1,224 |  |
| Corner & trim boards | 1x4x10 PT/cedar | 10 | $11.00 | $110 |  |

### Roof: $1,304

| Item | Spec | Qty | Unit | Total | Notes |
|---|---|---:|---:|---:|---|
| Ridge board | 2x8x12 | 2 | $18.00 | $36 |  |
| Rafters | 2x6x8 | 26 | $8.50 | $221 | incl. fly rafters |
| Rafter ties | 2x6x10 | 11 | $10.50 | $116 |  |
| Purlins | 2x4x12 | 16 | $8.00 | $128 |  |
| Steel roof panels | 29 ga ribbed 3 ft x 6.5 ft | 16 | $32.00 | $512 | cut-to-length at most yards |
| Vented ridge cap | 10 ft section | 3 | $28.00 | $84 |  |
| Rake/eave trim + closures | 10 ft pieces / strips | 12 | $12.00 | $144 |  |
| Roofing screws | #10 x 1-1/2 in. gasketed (250) | 2 | $32.00 | $64 |  |

### Fasteners & finish: $460

| Item | Spec | Qty | Unit | Total | Notes |
|---|---|---:|---:|---:|---|
| Framing nails / structural screws | assorted boxes | 1 | $160.00 | $160 |  |
| Construction adhesive | subfloor adhesive tubes | 6 | $7.00 | $42 |  |
| Exterior primer + paint | gallons | 5 | $42.00 | $210 |  |
| Caulk / sealant | tubes | 6 | $8.00 | $48 |  |

### Doors & windows: $222

| Item | Spec | Qty | Unit | Total | Notes |
|---|---|---:|---:|---:|---|
| People-door hardware | 3x 8 in. T-hinges + hasp + barrel bolt | 1 | $55.00 | $55 | door built from T1-11 offcuts |
| Window battens | 1x2x8 | 12 | $4.00 | $48 |  |
| Storm shutter hardware | hinges + hook-and-eye + prop sticks (shutters from T1-11 offcuts) | 4 | $8.00 | $32 | replaces polycarbonate panels |
| Pop door leaf + tracks | 1/2 in. HDPE 14x19 + 2x aluminium U-channel 4 ft | 1 | $45.00 | $45 |  |
| Manual pop-door rope kit | pulley + cleat + rope | 1 | $18.00 | $18 | Tier 1 door operation |
| Ramp | 2x10x6 + 1x2 cleats | 1 | $24.00 | $24 |  |

### Interior: $508

| Item | Spec | Qty | Unit | Total | Notes |
|---|---|---:|---:|---:|---|
| Nest bay plywood | 1/2 in. exterior plywood 4x8 | 3 | $45.00 | $135 |  |
| Nest bay lid | 3/4 in. exterior plywood 4x8 | 1 | $58.00 | $58 |  |
| Piano hinge + latches | 2x 36 in. hinge + 2 raccoon-proof latches | 1 | $45.00 | $45 |  |
| Roosts & poop board frame | 2x4x10 | 11 | $6.50 | $72 |  |
| Poop board | 3/4 in. plywood 4x8 | 2 | $55.00 | $110 |  |
| Nest pads | washable nest box liners | 12 | $3.00 | $36 |  |
| Pine shavings | compressed bale | 4 | $9.00 | $36 | initial deep-litter bed |
| PDZ | 40 lb bag | 1 | $16.00 | $16 |  |

### Predator proofing: $445

| Item | Spec | Qty | Unit | Total | Notes |
|---|---|---:|---:|---:|---|
| Hardware cloth (walls/vents/skirt) | 1/2 in. 19 ga 48 in. x 100 ft | 1 | $210.00 | $210 | coop openings + floor skirt + run lower wall |
| Hardware cloth (aprons) | 1/2 in. 19 ga 24 in. x 100 ft | 2 | $95.00 | $190 | run + coop apron |
| Fender washers + screws | 1 in. washers + 1-1/4 in. screws (bulk) | 1 | $45.00 | $45 |  |

### Feed & water (Tier 1): $754

| Item | Spec | Qty | Unit | Total | Notes |
|---|---|---:|---:|---:|---|
| Water drum | 30 gal food-grade drum | 1 | $20.00 | $20 | used food-grade drum (car wash / bakery / farm supply) |
| Drinker line | 3/4 in. PVC + fittings + 10 horizontal nipples | 1 | $55.00 | $55 |  |
| Drum bulkheads + ball valve | 3/4 in. and 1/2 in. bulkheads + valve | 1 | $32.00 | $32 |  |
| Drum stand | concrete blocks | 6 | $3.00 | $18 |  |
| Supply hose chain | vacuum breaker + Y-valve + 25 psi regulator + filter | 1 | $48.00 | $48 |  |
| Drinking-water hose | 5/8 in. lead-free 75 ft | 1 | $65.00 | $65 |  |
| Service station framing | 2x4x8 (station walls, doors, lid frame) | 10 | $4.80 | $48 | exterior feed + water cabinet on the east wall |
| Service station siding + doors | T1-11 5/8 in. 4x9 | 2 | $72.00 | $144 |  |
| Feed bin | 3/4 in. exterior plywood 4x8 (sloped-floor gravity bin ~350 lb) | 2 | $58.00 | $116 | fills from outside; feeds the indoor trough through the wall |
| Indoor feed trough | 48 in. galvanized trough + anti-waste grill + slide gate | 1 | $48.00 | $48 | replaces hanging feeders |
| Service station roof | 29 ga panel 3 ft x 8 ft + drip edge | 2 | $34.00 | $68 |  |
| Drum-side insulation | 1 in. rigid foam 4x8 | 1 | $32.00 | $32 | freeze protection for the drum side |
| Station hinges + latches | 4 T-hinges + 2 raccoon-proof latches + bin lid hinge | 1 | $48.00 | $48 |  |
| Station base blocks | solid concrete blocks | 4 | $3.00 | $12 |  |

### Run & fencing: $1,225

| Item | Spec | Qty | Unit | Total | Notes |
|---|---|---:|---:|---:|---|
| Run posts | 4x4x10 PT | 12 | $19.00 | $228 |  |
| Run rails | 2x4x10 PT | 16 | $8.50 | $136 |  |
| Run roof purlins | 2x4x12 | 7 | $8.00 | $56 |  |
| Welded wire | 2x4 in. 14 ga 48 in. x 100 ft | 1 | $120.00 | $120 |  |
| Aviary netting | 25x25 ft knotted 2 in. | 1 | $85.00 | $85 |  |
| Shade sail | 12 x 16 ft HDPE shade sail + ties (half the run) | 1 | $55.00 | $55 | replaces a steel-roofed run section |
| Walk gate kit + latches | gate hardware + 2 latches + carabiners | 1 | $70.00 | $70 |  |
| Electric poultry netting | 48 in. x 164 ft | 1 | $215.00 | $215 | move it between the 3 paddocks; add rolls later if wanted |
| Solar netting energizer | >=0.25 J solar + ground rod + tester | 1 | $260.00 | $260 |  |

### Power to coop: $1,406

| Item | Spec | Qty | Unit | Total | Notes |
|---|---|---:|---:|---:|---|
| Feeder cable | UF-B 12/2 w/G (per ft) | 75 | $1.60 | $120 | length depends on site |
| GFCI breaker | 20 A GFCI breaker for your panel | 1 | $55.00 | $55 |  |
| Mains enclosure | NEMA 4X/IP65 ~300x250x150 with DIN rail | 1 | $85.00 | $85 |  |
| DIN breaker | 2-pole 20 A DIN | 1 | $22.00 | $22 |  |
| GFCI receptacle + WR cover | 20 A WR GFCI + in-use cover | 1 | $38.00 | $38 |  |
| Light fixtures | wet-location jelly-jar + 9 W LED | 2 | $24.00 | $48 |  |
| Conduit & fittings | PVC conduit + boxes + glands | 1 | $90.00 | $90 |  |
| Electrician labour | feeder + mains box install + inspection (estimate) | 1 | $900.00 | $900 | varies widely by region |
| Heated winter waterer | plastic-safe 250 W drum de-icer | 1 | $48.00 | $48 |  |

## Tier 2: automation (controller, door, water, feed, sensors)

### Controller: $285

| Item | Spec | Qty | Unit | Total | Notes |
|---|---|---:|---:|---:|---|
| PCB (5 pcs incl. shipping) | coop-controller gerbers from pcb/fab | 1 | $35.00 | $35 | JLCPCB/PCBWay |
| PCB components | per pcb/fab/bom.csv (relays FETs terminal blocks regulator passives) | 1 | $62.00 | $62 | Digi-Key/Mouser/LCSC |
| ESP32 dev board | Espressif ESP32-DevKitC-32E | 1 | $11.00 | $11 |  |
| Controller enclosure | IP65 ABS ~250x200x100 | 1 | $32.00 | $32 |  |
| Cable glands | PG7/PG9 nylon assortment | 1 | $14.00 | $14 |  |
| Panel button + LED | IP67 momentary push button + 5 mm LED bezel | 1 | $12.00 | $12 |  |
| 12 V PSU | Mean Well HDR-100-12N DIN rail | 1 | $32.00 | $32 |  |
| DIN relay modules | 12 VDC coil, 6 A contact, with LED + suppression diode (Finder 38.51 or eq.) | 2 | $16.00 | $32 | lights + de-icer; genuine SSRs (Crydom D24xx) are the ~$100 alternative |
| 3D-printed parts | full set in PETG/ASA via print service | 1 | $55.00 | $55 | see 3d-printing/README.md |

### Door: $65

| Item | Spec | Qty | Unit | Total | Notes |
|---|---|---:|---:|---:|---|
| Linear actuator | 12 V 18 in. stroke >=225 N IP54+ with limit switches | 1 | $55.00 | $55 |  |
| Reed switches | surface-mount NO reed + magnet | 2 | $5.00 | $10 |  |

### Water: $126

| Item | Spec | Qty | Unit | Total | Notes |
|---|---|---:|---:|---:|---|
| Solenoid valve | 12 V NC 1/2 in. brass pilot-operated | 1 | $28.00 | $28 |  |
| Float switches | PP reed float level switch | 2 | $7.00 | $14 |  |
| Water temperature probe | DS18B20 waterproof 3 m | 1 | $5.00 | $5 |  |
| Overflow + inlet bulkheads | 3/4 in. overflow + 1/2 in. inlet + PVC | 1 | $24.00 | $24 |  |
| Drinker-line heat cable | self-regulating 3 W/ft 12 ft + insulation | 1 | $55.00 | $55 | cold climates |

### Feed: $12

| Item | Spec | Qty | Unit | Total | Notes |
|---|---|---:|---:|---:|---|
| Feed level sensor | JSN-SR04T waterproof ultrasonic | 1 | $12.00 | $12 | mounted in the feed-bin lid |

### Environment: $45

| Item | Spec | Qty | Unit | Total | Notes |
|---|---|---:|---:|---:|---|
| Temp/humidity/pressure | BME280 breakout (3.3 V) | 1 | $9.00 | $9 |  |
| Light sensor | BH1750 breakout | 1 | $4.00 | $4 |  |
| Exhaust fan | 12 V 4 in. inline blower | 1 | $32.00 | $32 |  |

### Security: $4

| Item | Spec | Qty | Unit | Total | Notes |
|---|---|---:|---:|---:|---|
| PIR sensor | HC-SR501 | 1 | $4.00 | $4 |  |

### Wiring: $108

| Item | Spec | Qty | Unit | Total | Notes |
|---|---|---:|---:|---:|---|
| Sprinkler wire | 18/5 direct-burial 250 ft | 1 | $48.00 | $48 |  |
| Outdoor 2-conductor | 16/2 outdoor 100 ft | 1 | $28.00 | $28 |  |
| Cat5e | outdoor Cat5e 50 ft | 1 | $14.00 | $14 |  |
| Ferrules + labels | ferrule kit + cable labels | 1 | $18.00 | $18 |  |

## Optional add-ons (camera, BLE sensors, battery backup, metered auger)

### Camera: $82

| Item | Spec | Qty | Unit | Total | Notes |
|---|---|---:|---:|---:|---|
| ESP32-CAM | AI-Thinker ESP32-CAM + MB programmer | 1 | $12.00 | $12 |  |
| Camera 5 V supply | 5 V 2 A weatherproof | 1 | $10.00 | $10 |  |
| PoE/WiFi camera (alternative) | RTSP/ONVIF outdoor camera with IR | 1 | $60.00 | $60 | better image than ESP32-CAM |

### BLE sensors: $10

| Item | Spec | Qty | Unit | Total | Notes |
|---|---|---:|---:|---:|---|
| BLE thermometer | Xiaomi LYWSD03MMC (pvvx firmware) | 2 | $5.00 | $10 |  |

### Backup power: $52

| Item | Spec | Qty | Unit | Total | Notes |
|---|---|---:|---:|---:|---|
| SLA battery | 12 V 7 Ah | 1 | $24.00 | $24 |  |
| Float charger + diode | 12 V float charger + 10 A Schottky OR-ing | 1 | $28.00 | $28 |  |

### Metered auger (optional): $70

| Item | Spec | Qty | Unit | Total | Notes |
|---|---|---:|---:|---:|---|
| Auger kit | 1-1/2 in. ship auger in 2 in. PVC + 12 V ~30 rpm gear motor + coupler (J5) | 1 | $70.00 | $70 | only if you want to ration feed; the gravity bin already feeds automatically |

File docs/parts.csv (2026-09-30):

tier | category | item | spec | qty | unit_price | notes
base | Site & foundation | Crushed stone | 3/4 in. clean crushed stone (cu yd) | 1.5 | 55 | 3 x 12 in. gravel strips under the skids + service-station base (full pad optional)
base | Site & foundation | Landscape fabric | 4 ft x 100 ft woven | 1 | 35
base | Site & foundation | Skids | 4x6x20 PT ground-contact | 3 | 75
base | Floor | Rim joists | 2x6x20 PT | 2 | 34
base | Floor | Floor joists | 2x6x10 PT | 16 | 14 | 16 in. o.c.
base | Floor | Joist hangers | 2x6 face-mount (Simpson LUS26 or eq.) | 28 | 1.6
base | Floor | Hurricane ties | H2.5A or eq. | 72 | 0.9 | joists-to-skids + rafters-to-plates
base | Floor | Subfloor | 3/4 in. PT plywood 4x8 | 7 | 68
base | Floor | Floor paint | porch & floor enamel 1 gal (2 coats on the PT plywood) | 1 | 55 | replaces sheet vinyl
base | Walls | Studs | 2x4x92-5/8 precut | 90 | 4.5
base | Walls | Gable studs | 2x4x8 | 6 | 4.8
base | Walls | Bottom plates | 2x4x10 PT | 7 | 8.5
base | Walls | Top plates | 2x4x10 | 14 | 6.5
base | Walls | Headers | 2x8x10 | 5 | 15
base | Walls | Siding | T1-11 5/8 in. 4x9 panel | 17 | 72
base | Walls | Corner & trim boards | 1x4x10 PT/cedar | 10 | 11
base | Roof | Ridge board | 2x8x12 | 2 | 18
base | Roof | Rafters | 2x6x8 | 26 | 8.5 | incl. fly rafters
base | Roof | Rafter ties | 2x6x10 | 11 | 10.5
base | Roof | Purlins | 2x4x12 | 16 | 8
base | Roof | Steel roof panels | 29 ga ribbed 3 ft x 6.5 ft | 16 | 32 | cut-to-length at most yards
base | Roof | Vented ridge cap | 10 ft section | 3 | 28
base | Roof | Rake/eave trim + closures | 10 ft pieces / strips | 12 | 12
base | Roof | Roofing screws | #10 x 1-1/2 in. gasketed (250) | 2 | 32
base | Fasteners & finish | Framing nails / structural screws | assorted boxes | 1 | 160
base | Fasteners & finish | Construction adhesive | subfloor adhesive tubes | 6 | 7
base | Fasteners & finish | Exterior primer + paint | gallons | 5 | 42
base | Fasteners & finish | Caulk / sealant | tubes | 6 | 8
base | Doors & windows | People-door hardware | 3x 8 in. T-hinges + hasp + barrel bolt | 1 | 55 | door built from T1-11 offcuts
base | Doors & windows | Window battens | 1x2x8 | 12 | 4
base | Doors & windows | Storm shutter hardware | hinges + hook-and-eye + prop sticks (shutters from T1-11 offcuts) | 4 | 8 | replaces polycarbonate panels
base | Doors & windows | Pop door leaf + tracks | 1/2 in. HDPE 14x19 + 2x aluminium U-channel 4 ft | 1 | 45
base | Doors & windows | Manual pop-door rope kit | pulley + cleat + rope | 1 | 18 | Tier 1 door operation
base | Doors & windows | Ramp | 2x10x6 + 1x2 cleats | 1 | 24
base | Interior | Nest bay plywood | 1/2 in. exterior plywood 4x8 | 3 | 45
base | Interior | Nest bay lid | 3/4 in. exterior plywood 4x8 | 1 | 58
base | Interior | Piano hinge + latches | 2x 36 in. hinge + 2 raccoon-proof latches | 1 | 45
base | Interior | Roosts & poop board frame | 2x4x10 | 11 | 6.5
base | Interior | Poop board | 3/4 in. plywood 4x8 | 2 | 55
base | Interior | Nest pads | washable nest box liners | 12 | 3
base | Interior | Pine shavings | compressed bale | 4 | 9 | initial deep-litter bed
base | Interior | PDZ | 40 lb bag | 1 | 16
base | Predator proofing | Hardware cloth (walls/vents/skirt) | 1/2 in. 19 ga 48 in. x 100 ft | 1 | 210 | coop openings + floor skirt + run lower wall
base | Predator proofing | Hardware cloth (aprons) | 1/2 in. 19 ga 24 in. x 100 ft | 2 | 95 | run + coop apron
base | Predator proofing | Fender washers + screws | 1 in. washers + 1-1/4 in. screws (bulk) | 1 | 45
base | Feed & water (Tier 1) | Water drum | 30 gal food-grade drum | 1 | 20 | used food-grade drum (car wash / bakery / farm supply)
base | Feed & water (Tier 1) | Drinker line | 3/4 in. PVC + fittings + 10 horizontal nipples | 1 | 55
base | Feed & water (Tier 1) | Drum bulkheads + ball valve | 3/4 in. and 1/2 in. bulkheads + valve | 1 | 32
base | Feed & water (Tier 1) | Drum stand | concrete blocks | 6 | 3
base | Feed & water (Tier 1) | Supply hose chain | vacuum breaker + Y-valve + 25 psi regulator + filter | 1 | 48
base | Feed & water (Tier 1) | Drinking-water hose | 5/8 in. lead-free 75 ft | 1 | 65
base | Feed & water (Tier 1) | Service station framing | 2x4x8 (station walls, doors, lid frame) | 10 | 4.8 | exterior feed + water cabinet on the east wall
base | Feed & water (Tier 1) | Service station siding + doors | T1-11 5/8 in. 4x9 | 2 | 72
base | Feed & water (Tier 1) | Feed bin | 3/4 in. exterior plywood 4x8 (sloped-floor gravity bin ~350 lb) | 2 | 58 | fills from outside; feeds the indoor trough through the wall
base | Feed & water (Tier 1) | Indoor feed trough | 48 in. galvanized trough + anti-waste grill + slide gate | 1 | 48 | replaces hanging feeders
base | Feed & water (Tier 1) | Service station roof | 29 ga panel 3 ft x 8 ft + drip edge | 2 | 34
base | Feed & water (Tier 1) | Drum-side insulation | 1 in. rigid foam 4x8 | 1 | 32 | freeze protection for the drum side
base | Feed & water (Tier 1) | Station hinges + latches | 4 T-hinges + 2 raccoon-proof latches + bin lid hinge | 1 | 48
base | Feed & water (Tier 1) | Station base blocks | solid concrete blocks | 4 | 3
base | Run & fencing | Run posts | 4x4x10 PT | 12 | 19
base | Run & fencing | Run rails | 2x4x10 PT | 16 | 8.5
base | Run & fencing | Run roof purlins | 2x4x12 | 7 | 8
base | Run & fencing | Welded wire | 2x4 in. 14 ga 48 in. x 100 ft | 1 | 120
base | Run & fencing | Aviary netting | 25x25 ft knotted 2 in. | 1 | 85
base | Run & fencing | Shade sail | 12 x 16 ft HDPE shade sail + ties (half the run) | 1 | 55 | replaces a steel-roofed run section
base | Run & fencing | Walk gate kit + latches | gate hardware + 2 latches + carabiners | 1 | 70
base | Run & fencing | Electric poultry netting | 48 in. x 164 ft | 1 | 215 | move it between the 3 paddocks; add rolls later if wanted
base | Run & fencing | Solar netting energizer | >=0.25 J solar + ground rod + tester | 1 | 260
base | Power to coop | Feeder cable | UF-B 12/2 w/G (per ft) | 75 | 1.6 | length depends on site
base | Power to coop | GFCI breaker | 20 A GFCI breaker for your panel | 1 | 55
base | Power to coop | Mains enclosure | NEMA 4X/IP65 ~300x250x150 with DIN rail | 1 | 85
base | Power to coop | DIN breaker | 2-pole 20 A DIN | 1 | 22
base | Power to coop | GFCI receptacle + WR cover | 20 A WR GFCI + in-use cover | 1 | 38
base | Power to coop | Light fixtures | wet-location jelly-jar + 9 W LED | 2 | 24
base | Power to coop | Conduit & fittings | PVC conduit + boxes + glands | 1 | 90
base | Power to coop | Electrician labour | feeder + mains box install + inspection (estimate) | 1 | 900 | varies widely by region
base | Power to coop | Heated winter waterer | plastic-safe 250 W drum de-icer | 1 | 48
auto | Controller | PCB (5 pcs incl. shipping) | coop-controller gerbers from pcb/fab | 1 | 35 | JLCPCB/PCBWay
auto | Controller | PCB components | per pcb/fab/bom.csv (relays FETs terminal blocks regulator passives) | 1 | 62 | Digi-Key/Mouser/LCSC
auto | Controller | ESP32 dev board | Espressif ESP32-DevKitC-32E | 1 | 11
auto | Controller | Controller enclosure | IP65 ABS ~250x200x100 | 1 | 32
auto | Controller | Cable glands | PG7/PG9 nylon assortment | 1 | 14
auto | Controller | Panel button + LED | IP67 momentary push button + 5 mm LED bezel | 1 | 12
auto | Controller | 12 V PSU | Mean Well HDR-100-12N DIN rail | 1 | 32
auto | Controller | DIN relay modules | 12 VDC coil, 6 A contact, with LED + suppression diode (Finder 38.51 or eq.) | 2 | 16 | lights + de-icer; genuine SSRs (Crydom D24xx) are the ~$100 alternative
auto | Controller | 3D-printed parts | full set in PETG/ASA via print service | 1 | 55 | see 3d-printing/README.md
auto | Door | Linear actuator | 12 V 18 in. stroke >=225 N IP54+ with limit switches | 1 | 55
auto | Door | Reed switches | surface-mount NO reed + magnet | 2 | 5
auto | Water | Solenoid valve | 12 V NC 1/2 in. brass pilot-operated | 1 | 28
auto | Water | Float switches | PP reed float level switch | 2 | 7
auto | Water | Water temperature probe | DS18B20 waterproof 3 m | 1 | 5
auto | Water | Overflow + inlet bulkheads | 3/4 in. overflow + 1/2 in. inlet + PVC | 1 | 24
auto | Feed | Feed level sensor | JSN-SR04T waterproof ultrasonic | 1 | 12 | mounted in the feed-bin lid
auto | Environment | Temp/humidity/pressure | BME280 breakout (3.3 V) | 1 | 9
auto | Environment | Light sensor | BH1750 breakout | 1 | 4
auto | Environment | Exhaust fan | 12 V 4 in. inline blower | 1 | 32
auto | Security | PIR sensor | HC-SR501 | 1 | 4
auto | Wiring | Sprinkler wire | 18/5 direct-burial 250 ft | 1 | 48
auto | Wiring | Outdoor 2-conductor | 16/2 outdoor 100 ft | 1 | 28
auto | Wiring | Cat5e | outdoor Cat5e 50 ft | 1 | 14
auto | Wiring | Ferrules + labels | ferrule kit + cable labels | 1 | 18
auto | Water | Drinker-line heat cable | self-regulating 3 W/ft 12 ft + insulation | 1 | 55 | cold climates
opt | Camera | ESP32-CAM | AI-Thinker ESP32-CAM + MB programmer | 1 | 12
opt | Camera | Camera 5 V supply | 5 V 2 A weatherproof | 1 | 10
opt | BLE sensors | BLE thermometer | Xiaomi LYWSD03MMC (pvvx firmware) | 2 | 5
opt | Backup power | SLA battery | 12 V 7 Ah | 1 | 24
opt | Backup power | Float charger + diode | 12 V float charger + 10 A Schottky OR-ing | 1 | 28
opt | Camera | PoE/WiFi camera (alternative) | RTSP/ONVIF outdoor camera with IR | 1 | 60 | better image than ESP32-CAM
opt | Metered auger (optional) | Auger kit | 1-1/2 in. ship auger in 2 in. PVC + 12 V ~30 rpm gear motor + coupler (J5) | 1 | 70 | only if you want to ration feed; the gravity bin already feeds automatically

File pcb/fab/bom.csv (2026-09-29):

Qty | References | Value | Footprint | Notes
1 | C1 | 470uF 25V | CP_Radial_D10.0mm_P5.00mm
1 | C2 | 47uF 10V | CP_Radial_D6.3mm_P2.50mm
8 | C3 C4 C5 C6 C7 C8 C9 C10 | 100nF | C_Disc_D5.0mm_W2.5mm_P5.00mm
1 | D1 | SB560 | D_DO-201AD_P15.24mm_Horizontal | Reverse-polarity protection
1 | D2 | P6KE15CA | D_DO-15_P10.16mm_Horizontal
2 | D3 D4 | 1N4148 | D_DO-35_SOD27_P7.62mm_Horizontal
3 | D5 D6 D7 | 1N5822 | D_DO-201AD_P15.24mm_Horizontal
1 | D9 | PWR green | LED_D3.0mm
1 | F1 | 5A slow-blow 5x20 | Fuseholder_Cylinder-5x20mm_Schurter_0031_8201_Horizontal_Open
1 | J1 | PWR_IN_12V | TerminalBlock_Phoenix_MKDS-1,5-2-5.08_1x02_P5.08mm_Horizontal
1 | J2 | ACTUATOR | TerminalBlock_Phoenix_MKDS-1,5-2-5.08_1x02_P5.08mm_Horizontal
1 | J3 | DOOR_SW | TerminalBlock_Phoenix_MKDS-1,5-3-5.08_1x03_P5.08mm_Horizontal
1 | J4 | VALVE | TerminalBlock_Phoenix_MKDS-1,5-2-5.08_1x02_P5.08mm_Horizontal
1 | J5 | FEEDER | TerminalBlock_Phoenix_MKDS-1,5-2-5.08_1x02_P5.08mm_Horizontal
1 | J6 | SSR_OUT | TerminalBlock_Phoenix_MKDS-1,5-4-5.08_1x04_P5.08mm_Horizontal
1 | J7 | WATER_LVL | TerminalBlock_Phoenix_MKDS-1,5-3-5.08_1x03_P5.08mm_Horizontal
1 | J8 | ONEWIRE | TerminalBlock_Phoenix_MKDS-1,5-3-5.08_1x03_P5.08mm_Horizontal
1 | J9 | I2C | TerminalBlock_Phoenix_MKDS-1,5-4-5.08_1x04_P5.08mm_Horizontal
1 | J10 | PIR | TerminalBlock_Phoenix_MKDS-1,5-3-5.08_1x03_P5.08mm_Horizontal
1 | J11 | ULTRASONIC | TerminalBlock_Phoenix_MKDS-1,5-4-5.08_1x04_P5.08mm_Horizontal
1 | J12 | PANEL | TerminalBlock_Phoenix_MKDS-1,5-4-5.08_1x04_P5.08mm_Horizontal
1 | J13 | EXPANSION | PinHeader_1x06_P2.54mm_Vertical
1 | J14 | FAN | TerminalBlock_Phoenix_MKDS-1,5-2-5.08_1x02_P5.08mm_Horizontal
1 | J20 | ESP32_DEVKITC_LEFT | PinSocket_1x19_P2.54mm_Vertical
1 | J21 | ESP32_DEVKITC_RIGHT_25.4mm | PinSocket_1x19_P2.54mm_Vertical | Fit for official Espressif DevKitC (25.4 mm rows)
1 | J22 | ESP32_DEVKITC_RIGHT_22.86mm | PinSocket_1x19_P2.54mm_Vertical | Fit instead of J21 for 22.86 mm clone boards
2 | K1 K2 | SRD-12VDC-SL-C | Relay_SPDT_SANYOU_SRD_Series_Form_C
4 | Q1 Q2 Q5 Q6 | 2N7000 | TO-92_Inline_Wide
3 | Q3 Q4 Q7 | IRLZ44N | TO-220-3_Vertical | Logic-level N-FET; IRLB8721 is a drop-in alternative
7 | R1 R3 R5 R7 R9 R11 R13 | 100R | R_Axial_DIN0207_L6.3mm_D2.5mm_P10.16mm_Horizontal
8 | R2 R4 R6 R8 R10 R12 R14 R31 | 100k | R_Axial_DIN0207_L6.3mm_D2.5mm_P10.16mm_Horizontal
6 | R15 R16 R17 R18 R19 R20 | 10k | R_Axial_DIN0207_L6.3mm_D2.5mm_P10.16mm_Horizontal
3 | R21 R22 R23 | 4.7k | R_Axial_DIN0207_L6.3mm_D2.5mm_P10.16mm_Horizontal
2 | R24 R30 | 1k | R_Axial_DIN0207_L6.3mm_D2.5mm_P10.16mm_Horizontal
1 | R25 | 2k | R_Axial_DIN0207_L6.3mm_D2.5mm_P10.16mm_Horizontal
1 | R26 | 330R | R_Axial_DIN0207_L6.3mm_D2.5mm_P10.16mm_Horizontal
1 | R32 | 22k | R_Axial_DIN0207_L6.3mm_D2.5mm_P10.16mm_Horizontal
1 | U1 | R-78E5.0-1.0 | Converter_DCDC_RECOM_R-78E-0.5_THT | Any 7805-pinout 5 V switching regulator >= 1 A (R-78E5.0-1.0, TSR 1-2450)

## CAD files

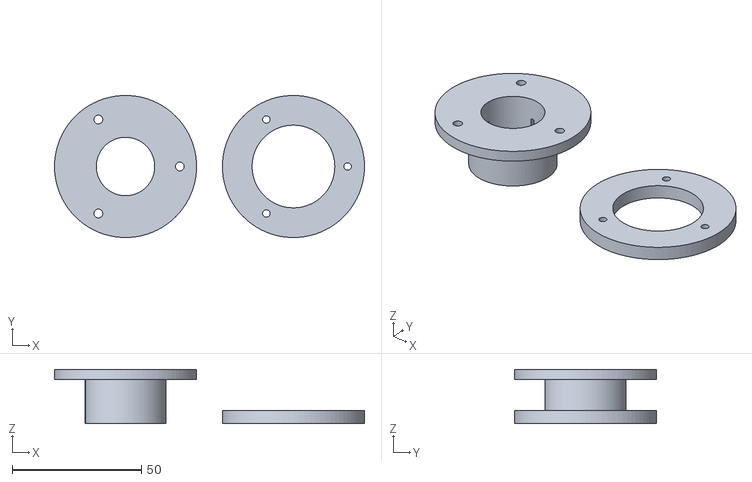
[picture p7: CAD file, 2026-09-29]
3d-printing/stl/ultrasonic_lid_mount.stl
120.0 x 55.0 x 21.0

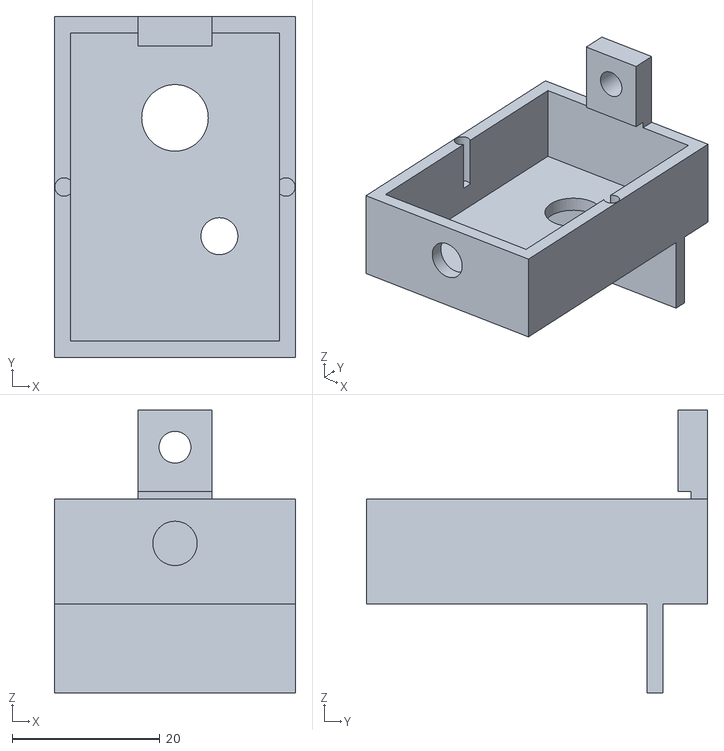
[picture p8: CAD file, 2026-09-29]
3d-printing/stl/camera_case.stl
32.6 x 46.1 x 38.2

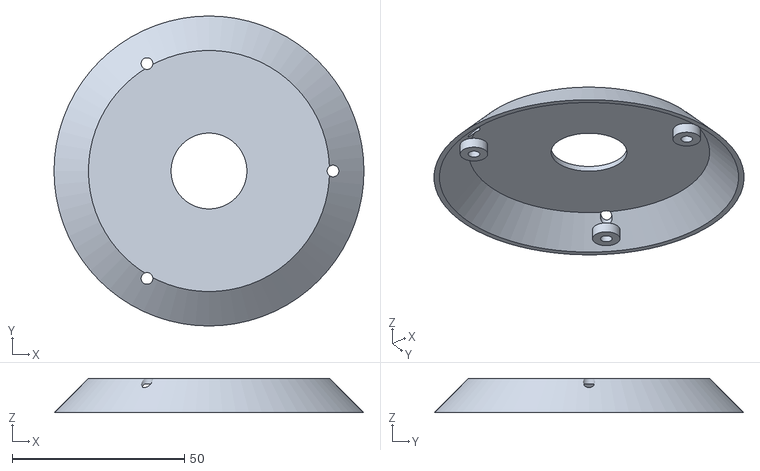
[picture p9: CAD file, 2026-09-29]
3d-printing/stl/shield_louvre_x4.stl
90.0 x 90.0 x 10.0

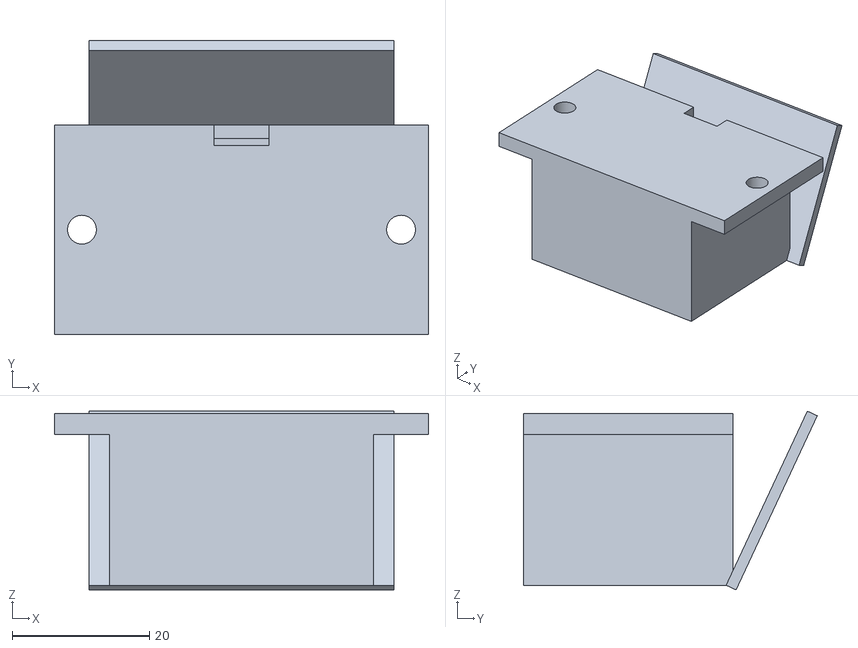
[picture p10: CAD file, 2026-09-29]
3d-printing/stl/pir_housing.stl
54.5 x 42.8 x 26.1

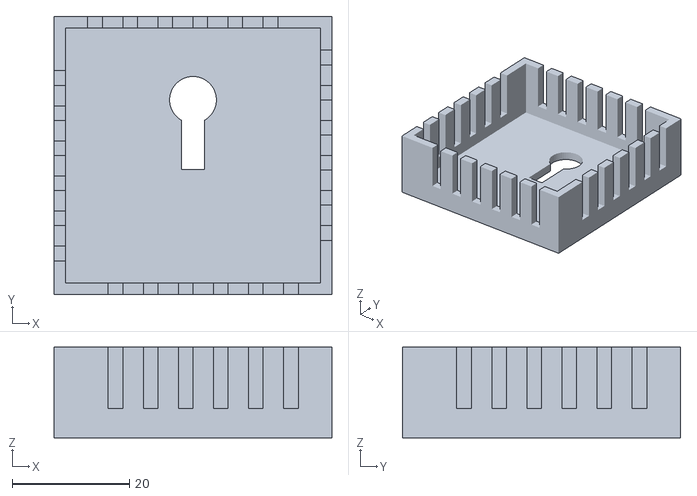
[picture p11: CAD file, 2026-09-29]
3d-printing/stl/ble_case_base.stl
47.5 x 47.5 x 15.5

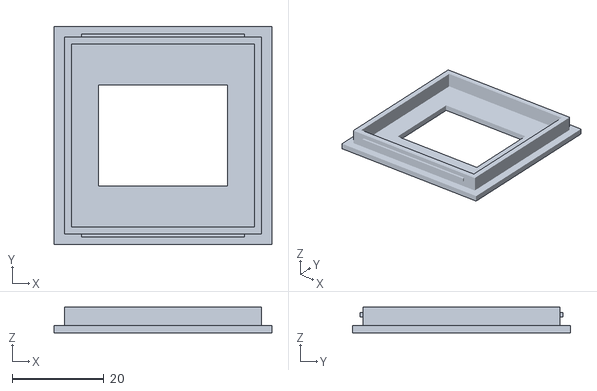
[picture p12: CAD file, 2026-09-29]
3d-printing/stl/ble_case_lid.stl
47.5 x 47.5 x 5.60

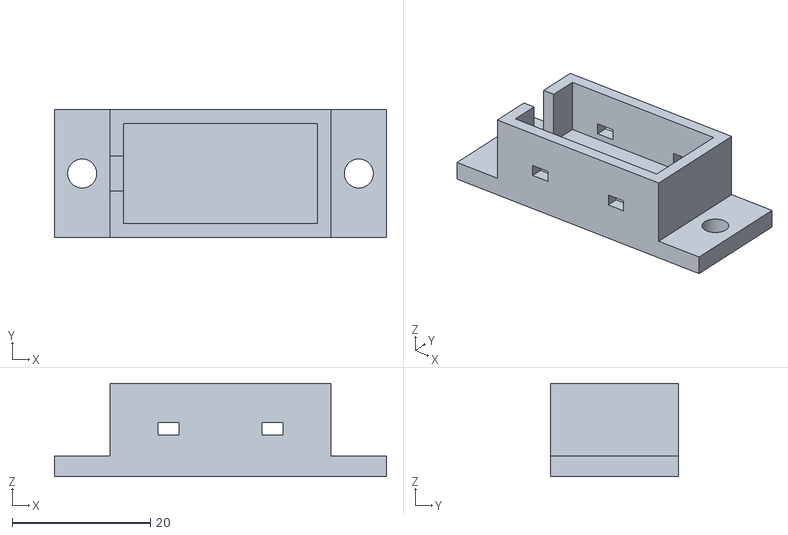
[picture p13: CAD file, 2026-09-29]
3d-printing/stl/reed_magnet_holder_x2.stl
48.0 x 18.5 x 13.5

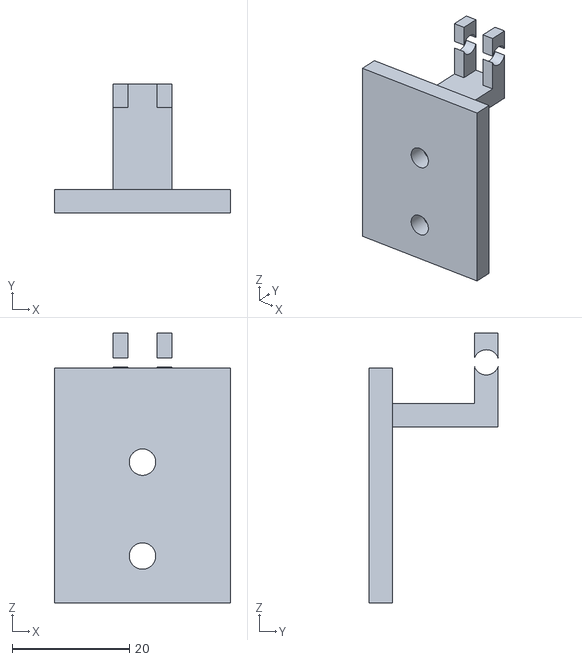
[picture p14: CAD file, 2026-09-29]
3d-printing/stl/camera_bracket.stl
30.0 x 22.0 x 46.0

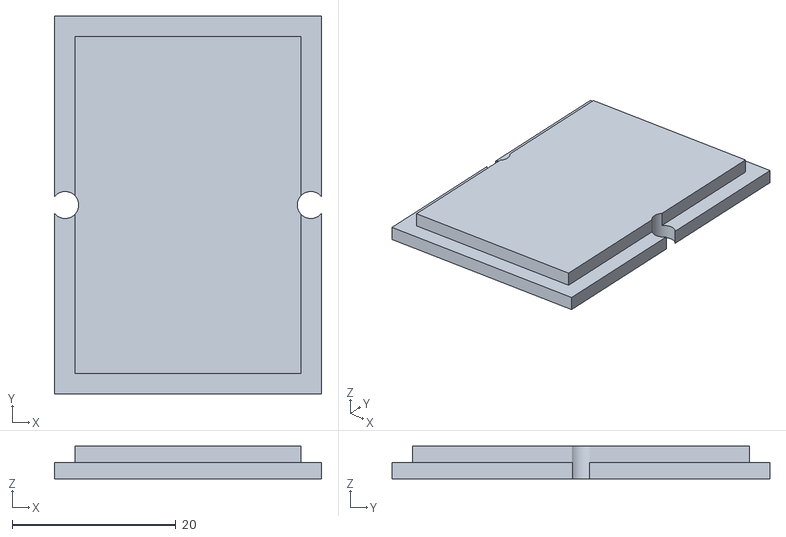
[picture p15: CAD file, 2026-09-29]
3d-printing/stl/camera_lid.stl
32.6 x 46.1 x 4.00

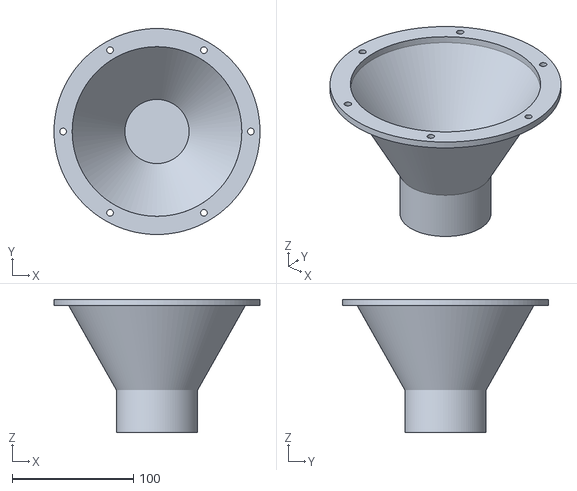
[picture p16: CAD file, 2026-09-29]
3d-printing/stl/feeder_funnel_adapter.stl
170.0 x 170.0 x 110.0

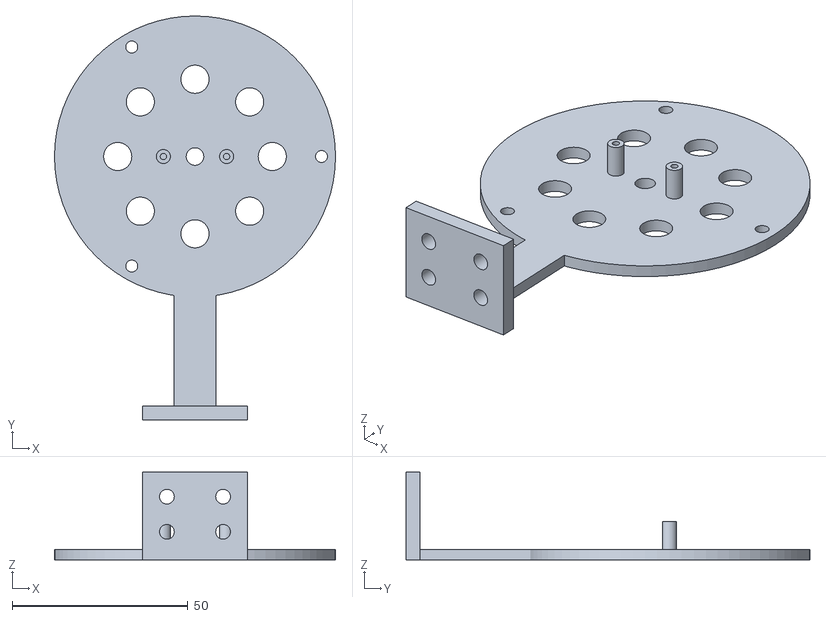
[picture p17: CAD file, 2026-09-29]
3d-printing/stl/shield_base.stl
80.0 x 115.0 x 25.0

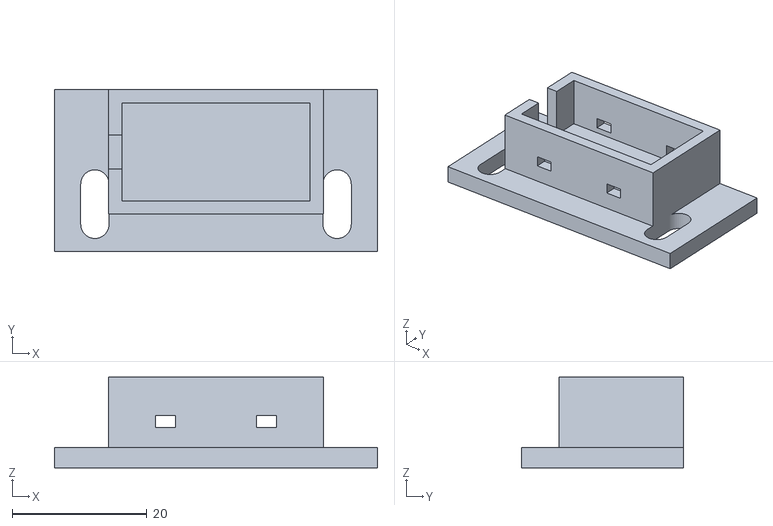
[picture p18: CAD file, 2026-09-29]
3d-printing/stl/reed_switch_bracket_x2.stl
48.0 x 24.0 x 13.5

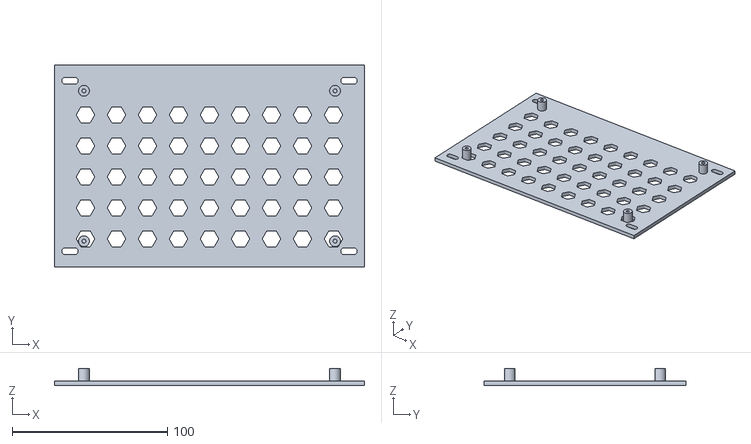
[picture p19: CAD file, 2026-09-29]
3d-printing/stl/controller_backplate.stl
200.0 x 130.0 x 11.0

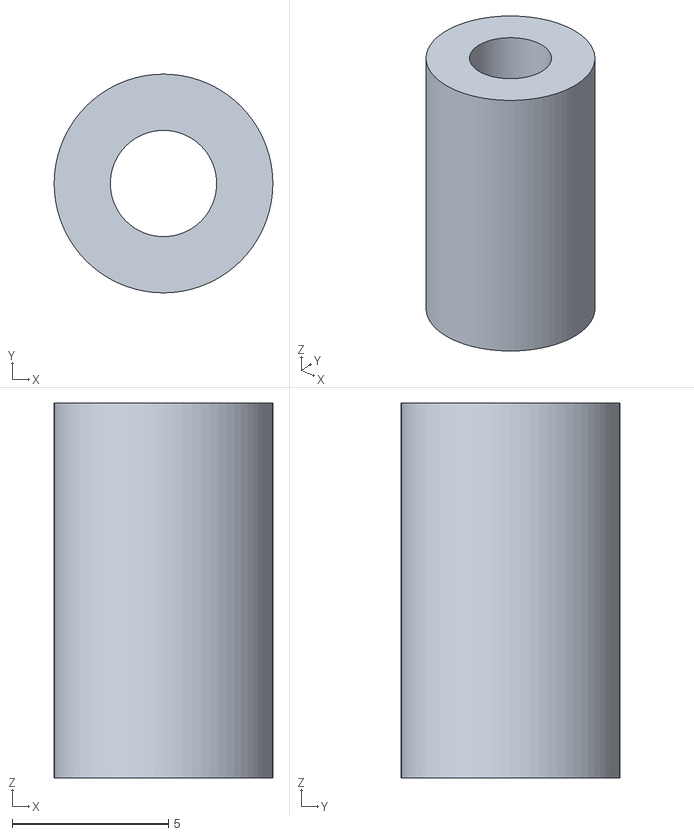
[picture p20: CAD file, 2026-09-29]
3d-printing/stl/shield_spacer_x12.stl
7.00 x 7.00 x 12.0

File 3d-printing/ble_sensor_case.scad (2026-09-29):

// Vented, peck-proof case for a Xiaomi LYWSD03MMC BLE thermometer (pvvx firmware), for
// the nest-box row or brooder. Slots let air through but are narrow enough to stop
// beaks, and a keyhole on the back hangs it on a screw.
// Print: PETG, 3 perimeters, 20% infill, no supports. Snap lid.

part = "all";   // "base" | "lid" | "all"
$fn = 48;

sensor = [43.5, 43.5, 13.5];   // LYWSD03MMC body + clearance
wall = 2;
slot_w = 2.5;
slot_pitch = 6;
inner = sensor;
outer = [inner[0] + 2 * wall, inner[1] + 2 * wall, inner[2] + wall];

module vents(len, n) {
    for (i = [0 : n - 1]) translate([i * slot_pitch, 0, 0]) cube([slot_w, len, 50]);
}

module base() {
    difference() {
        cube(outer);
        translate([wall, wall, wall]) cube([inner[0], inner[1], inner[2] + 1]);
        // side vent slots (all four walls)
        n = floor((inner[0] - 6) / slot_pitch);
        for (r = [0, 90, 180, 270])
            translate([outer[0] / 2, outer[1] / 2, 0]) rotate([0, 0, r])
                translate([-n * slot_pitch / 2, outer[1] / 2 - wall - 1, wall + 3])
                    vents(wall + 2, n);
        // keyhole on the back (floor)
        translate([outer[0] / 2, outer[1] * 0.7, -1]) cylinder(d = 8, h = wall + 2);
        translate([outer[0] / 2 - 2, outer[1] * 0.45, -1]) cube([4, outer[1] * 0.25, wall + 2]);
        // snap grooves
        for (y = [wall + 0.01, outer[1] - wall - 0.8])
            translate([wall, y, outer[2] - 3]) cube([inner[0], 0.8, 1.2]);
    }
}

module lid() {
    difference() {
        union() {
            cube([outer[0], outer[1], 1.6]);
            translate([wall + 0.25, wall + 0.25, 1.6]) difference() {
                cube([inner[0] - 0.5, inner[1] - 0.5, 4]);
                translate([1.6, 1.6, -1]) cube([inner[0] - 3.7, inner[1] - 3.7, 6]);
            }
            // snap bumps
            for (y = [wall + 0.25 - 0.6, outer[1] - wall - 0.25])
                translate([wall + 4, y, 3.4]) cube([inner[0] - 8, 0.6, 1]);
        }
        // viewing window so the display is readable
        translate([outer[0] / 2 - 14, outer[1] / 2 - 11, -1]) cube([28, 22, 4]);
    }
}

if (part == "base") base();
else if (part == "lid") lid();
else { base(); translate([outer[0] + 8, 0, 0]) lid(); }

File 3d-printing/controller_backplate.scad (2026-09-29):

// Mounting back-plate for the Coop Controller PCB (170 x 105 mm, M3 holes 4 mm in from
// each corner) inside an IP65 ABS/polycarbonate junction box, 250 x 200 mm or larger.
// Standoffs lift the PCB 8 mm. Slots on the plate match most boxes' internal bosses;
// or just drill the plate to suit.
// Print: PETG/ASA, 3 perimeters, 20% infill. Fits a 256 mm bed diagonally if needed.

$fn = 40;

pcb = [170, 105];
hole_inset = 4;
standoff_h = 8;
standoff_d = 7;
m3_pilot = 2.6;          // self-tapping M3, or use a heat-set insert (4.2 mm hole)
plate = [200, 130, 3];
box_boss_pitch = [180, 110];   // mounting slots for the box bosses (adjust to your box)

difference() {
    union() {
        // ribbed plate (lighter than solid)
        difference() {
            cube(plate);
            for (x = [20 : 20 : plate[0] - 20]) for (y = [18 : 20 : plate[1] - 18])
                translate([x, y, -1]) cylinder(d = 12, h = plate[2] + 2, $fn = 6);
        }
        // frame around the cut-outs
        difference() { cube(plate); translate([6, 6, -1]) cube([plate[0] - 12, plate[1] - 12, plate[2] + 2]); }
        // standoffs
        ox = (plate[0] - pcb[0]) / 2; oy = (plate[1] - pcb[1]) / 2;
        for (x = [hole_inset, pcb[0] - hole_inset]) for (y = [hole_inset, pcb[1] - hole_inset])
            translate([ox + x, oy + y, 0]) cylinder(d = standoff_d, h = plate[2] + standoff_h);
    }
    ox = (plate[0] - pcb[0]) / 2; oy = (plate[1] - pcb[1]) / 2;
    for (x = [hole_inset, pcb[0] - hole_inset]) for (y = [hole_inset, pcb[1] - hole_inset])
        translate([ox + x, oy + y, 1]) cylinder(d = m3_pilot, h = plate[2] + standoff_h);
    // box mounting slots
    for (sx = [-1, 1]) for (sy = [-1, 1])
        translate([plate[0] / 2 + sx * box_boss_pitch[0] / 2, plate[1] / 2 + sy * box_boss_pitch[1] / 2, -1])
            hull() { translate([-3, 0, 0]) cylinder(d = 4.5, h = 5); translate([3, 0, 0]) cylinder(d = 4.5, h = 5); }
}

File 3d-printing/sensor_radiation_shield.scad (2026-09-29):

// Louvred radiation shield (mini Stevenson screen) for the BME280 coop sensor. It keeps
// sun, radiant heat from the roof and dust off the sensor while air flows through.
// Stack N plates on 3x M3 threaded rods (or long M3 screws) with printed spacers.
// part = "plate" | "top" | "spacer" | "base" | "all"
// Print: white ASA/PETG (white matters for UV and heat), 2 perimeters, 15% infill.

part = "all";
$fn = 72;

d = 90;            // plate diameter
cone_h = 10;       // louvre drop
t = 1.6;           // plate thickness
hole_d = 22;       // centre opening for air + sensor cable
rod_d = 3.4;
rod_r = 36;
spacer_h = 12;

module rods(h) { for (a = [0, 120, 240]) rotate([0, 0, a]) translate([rod_r, 0, -1]) cylinder(d = rod_d, h = h + 2); }

module louvre(open = true) {
    difference() {
        cylinder(d1 = d, d2 = d - 2 * cone_h, h = cone_h);
        translate([0, 0, -t]) cylinder(d1 = d, d2 = d - 2 * cone_h, h = cone_h);
        if (open) cylinder(d = hole_d, h = cone_h * 3, center = true);
        rods(cone_h);
    }
    // rod bosses
    for (a = [0, 120, 240]) rotate([0, 0, a]) translate([rod_r, 0, 0])
        difference() { cylinder(d = 8, h = 3); cylinder(d = rod_d, h = 7, center = true); }
}

module base_plate() {
    // bottom plate: sensor cradle (BME280 breakout ~ 15 x 12 mm) + wall bracket arm
    difference() {
        union() {
            cylinder(d = d - 10, h = 3);
            translate([-6, -d / 2 - 30, 0]) cube([12, 40, 3]);          // arm
            translate([-15, -d / 2 - 30, 0]) cube([30, 4, 25]);         // wall flange
        }
        rods(3);
        for (z = [8, 18]) translate([-8, -d / 2 - 31, z]) rotate([-90, 0, 0]) cylinder(d = 4.2, h = 6);
        for (z = [8, 18]) translate([8, -d / 2 - 31, z]) rotate([-90, 0, 0]) cylinder(d = 4.2, h = 6);
        // air holes
        for (a = [0 : 45 : 359]) rotate([0, 0, a]) translate([22, 0, -1]) cylinder(d = 8, h = 5);
        cylinder(d = 5, h = 7, center = true);   // cable
    }
    // sensor clip posts
    for (x = [-9, 9]) translate([x, 0, 3]) difference() { cylinder(d = 4, h = 8); cylinder(d = 1.8, h = 9); }
}

module spacer() { difference() { cylinder(d = 7, h = spacer_h); cylinder(d = rod_d, h = spacer_h * 3, center = true); } }

if (part == "plate") louvre(true);
else if (part == "top") louvre(false);
else if (part == "spacer") spacer();
else if (part == "base") base_plate();
else {
    base_plate();
    translate([d + 10, 0, 0]) louvre(true);
    translate([2 * d + 20, 0, 0]) louvre(false);
    translate([0, d + 10, 0]) spacer();
}

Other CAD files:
3d-printing/stl/shield_top.stl
3d-printing/camera_mount.scad
3d-printing/feeder_funnel_adapter.scad
3d-printing/pir_mount.scad
3d-printing/reed_switch_bracket.scad
3d-printing/ultrasonic_lid_mount.scad
construction/model/coop_model.scad

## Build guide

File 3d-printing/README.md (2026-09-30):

# 3D-Printed Parts

All parts are parametric **OpenSCAD** sources. Ready-to-print STLs are in `stl/`, and
`bash render.sh` regenerates them (it fails on any OpenSCAD error or empty mesh).

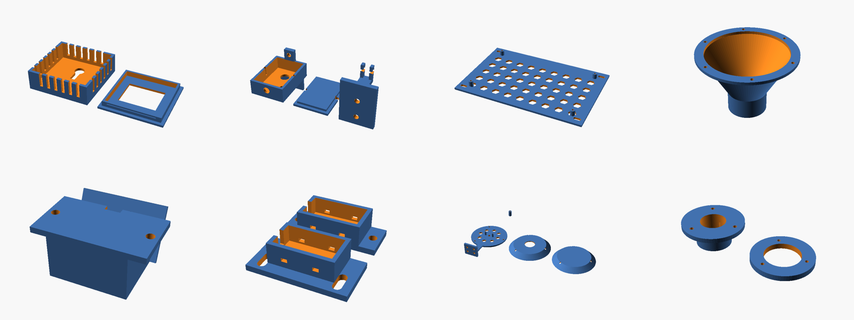
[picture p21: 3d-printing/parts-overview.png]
parts


| STL | Qty | Source | What it's for | Material |
|---|---|---|---|---|
| `feeder_funnel_adapter` | 0–1 | `feeder_funnel_adapter.scad` | **Only for the optional metered auger:** hopper floor → 2" PVC auger tube funnel. Not needed with the default gravity feed bin | PETG |
| `camera_case`, `camera_lid`, `camera_bracket` | 1 each | `camera_mount.scad` | ESP32-CAM hood, lid and tilting wall bracket (optional camera) | ASA / PETG |
| `pir_housing` | 1 | `pir_mount.scad` | HC-SR501 PIR housing, tilted 30° down over the roosts | PETG |
| `ble_case_base`, `ble_case_lid` | 1 per sensor | `ble_sensor_case.scad` | Vented, peck-proof case for a LYWSD03MMC BLE thermometer | PETG |
| `shield_base` | 1 | `sensor_radiation_shield.scad` | Radiation-shield base + wall arm, cradles the BME280 | **White** ASA/PETG |
| `shield_louvre_x4` | 4 | 〃 | Louvre plates | White ASA/PETG |
| `shield_top` | 1 | 〃 | Solid top plate | White ASA/PETG |
| `shield_spacer_x12` | 12 | 〃 | 12 mm spacers on 3× M3 rods | Any |
| `reed_switch_bracket_x2` | 2 | `reed_switch_bracket.scad` | Door-frame reed switch mounts with 12 mm slot adjustment | PETG |
| `reed_magnet_holder_x2` | 2 | 〃 | Matching magnet holders on the door leaf | PETG |
| `ultrasonic_lid_mount` | 1 | `ultrasonic_lid_mount.scad` | JSN-SR04T probe gland + clamp ring for the feed-bin lid in the service station (32 mm hole) | PETG |
| `controller_backplate` | 1 | `controller_backplate.scad` | Mounts the 170×105 mm controller PCB in an IP65 box (200×130 mm plate) | PETG |

## Material and settings

- Use **PETG** for most parts. It tolerates the humidity and ammonia in a coop and doesn't
  soften in summer like PLA does. Use **ASA** for anything in direct sun (camera, radiation
  shield), because it's UV-stable.
- **Avoid PLA outdoors.** It creeps and gets brittle within a season in a hot coop.
- Default settings: 0.2 mm layers, 3–4 perimeters, 20–30% gyroid infill. No supports are
  needed if you print each part flat side down (noted in each `.scad` header).
- Before printing, measure the parts that vary between suppliers and edit the parameters
  at the top of the `.scad` file: ESP32-CAM board, HC-SR501 dome, JSN-SR04T diameter,
  reed-switch body, and the PVC OD for your pipe.

## Using a print service

No printer? Upload the STLs to any of these:

| Service | Notes |
|---|---|
| **JLC3DP** (jlcpcb.com/3d-printing) | Cheapest. Add the parts to the same order as the PCB to share shipping. Pick "PETG" or "ASA" under FDM |
| **Craftcloud** (craftcloud3d.com) | Price comparison across local print shops |
| **PCBWay 3D printing** | Also combine with the PCB order |
| **Local library / makerspace** | Often free or at cost |

Rough cost for the default set (no funnel) in PETG through a service: **$30–55**. The
back-plate accounts for most of it.

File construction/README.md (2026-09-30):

# Construction

| Document | Contents |
|---|---|
| [coop-build-plan.md](coop-build-plan.md) | Full 10 × 20 ft coop build: foundation → roof, cut list, nest bay, roosts, pop door, **exterior feed & water service station**, ventilation, maintenance |
| [wiring.md](wiring.md) | 120 V feeder + mains box (electrician), 12 V controller terminal-by-terminal wiring, load budget |
| [plumbing.md](plumbing.md) | Spigot → backflow → regulator → filter → solenoid → drum (in the exterior station) → through the wall → drinkers, float logic, winterising |
| [run-and-fencing.md](run-and-fencing.md) | 500 sq ft secure run, buried apron, rotational electric-netting paddocks |

## Renders

Illustrative OpenSCAD model (`model/coop_model.scad`). Regenerate with `bash model/render.sh`,
which needs a desktop OpenSCAD because PNG export uses OpenGL.

| | |
|---|---|
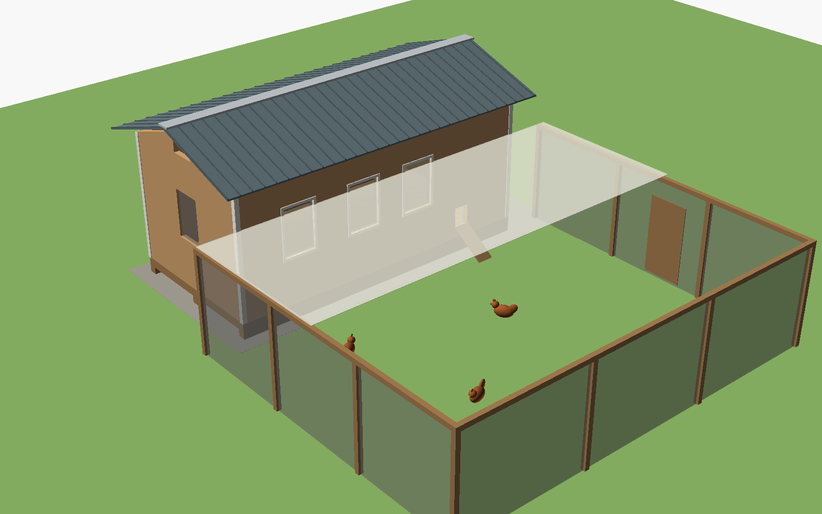
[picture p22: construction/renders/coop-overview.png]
|  Exterior from the south-east: run, windows with shutters, service station |  Overview with the secure run and shade sail |
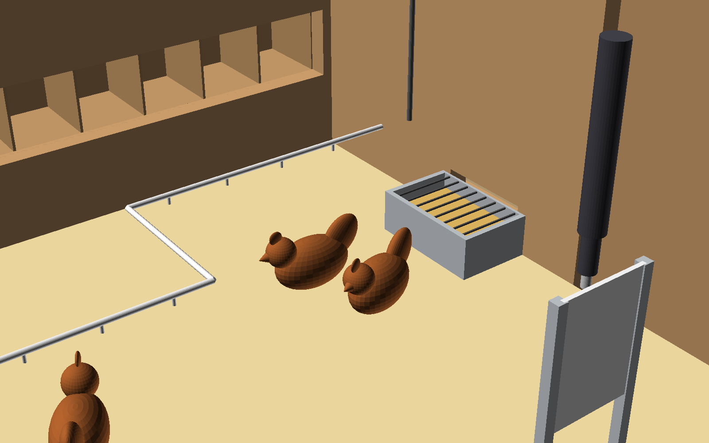
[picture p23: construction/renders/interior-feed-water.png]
|  **Service station, doors open:** gravity feed bin (sloped floor to the wall slot), 30 gal drum, 12 V valve |  **Inside:** trough fed through the wall, nipple line from the exterior drum, pop door + actuator |
|  Interior cutaway: roosts over the poop board, nest openings, drinkers, trough, electrical boxes |  Nest bay with the lid open (eggs collected from outside) |

## Diagrams

`diagrams/` is generated by `gen_diagrams.py`; the wiring diagram reads
`hardware/pinmap.yaml`.

| | |
|---|---|
|  |  |
|  |  |
|  | |

> Structural and electrical work need local code review: get a permit if required,
> check the snow/wind loads, and have a licensed electrician do the 120 V side.

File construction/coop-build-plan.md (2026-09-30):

# 50-Bird Coop: Construction Plan

> **SAFETY / CODE.** This is a 10 × 20 ft framed building. Many jurisdictions need a
> permit for accessory structures over 120–200 sq ft, and setbacks from property lines
> and wells apply. Check your **ground snow load and design wind speed** with your
> building department, and size the rafters from a span table for that load. The framing
> below suits roughly **30 psf ground snow and 115 mph wind**. Heavier loads need 2×8
> rafters or 16" spacing. All 120 V work is covered separately in `wiring.md` and needs a
> licensed electrician.

exterior render

floor plan
elevations

More pictures are in [`renders/`](renders/): an interior cutaway, the open service station and the open nest bay.

## 1. Design summary

| Item | Spec |
|---|---|
| Footprint | 10 ft × 20 ft outside (≈ 188 sq ft usable inside, 4 sq ft/bird) plus an exterior nest bay and an exterior feed/water service station |
| Foundation | 3 × 4×6 PT skids on compacted gravel strips (a full pad is optional). Floor ≈ 12" above grade |
| Floor | 2×6 PT joists 16" o.c., ¾" PT plywood, 2 coats of porch & floor enamel, 8–12" deep litter |
| Walls | 2×4 studs 16" o.c. (92⅝" precuts, 8'-1" walls), T1-11 siding |
| Roof | 4/12 gable, 2×6 rafters 24" o.c. + 2×6 rafter ties, 2×4 purlins, 29 ga ribbed steel, vented ridge, 12" overhangs |
| Ventilation | ≥ 20 sq ft: open soffits both eaves (screened), ridge vent, gable vents, 4 windows |
| Openings | 36" people door (east), 12 × 16" pop door (south), 4 × 24 × 36" windows, 12-box nest bay (north), feed slot + water pipe through the east wall |
| Feed & water | **Filled from outside.** A ~350 lb gravity feed bin and a 30 gal drum sit in a roofed, lockable station on the east wall. Feed flows through a wall slot into an indoor trough, and water is piped through the wall to the nipple line (§7) |
| Roosts | 5 × 9 ft 2×4 (wide face up), 36–40" high, 13" apart, over a 24"-high poop board |
| Predator proofing | ½" 19-ga hardware cloth on **every** opening and skirting the raised floor, a 24" buried apron, 2-step latches |

Put the long south wall with the windows toward the sun. Partial shade from deciduous
trees to the west/south-west is ideal: summer shade, winter sun.

## 2. Build sequence

1. **Site and gravel strips.** Strip the sod on a 12 × 22 ft area (plus 3 × 6 ft for the
   service station). Dig three 12"-wide, 4"-deep trenches under the skid lines, line them
   with landscape fabric, and fill with ¾" crushed stone in compacted lifts. Level the
   strips to within ¼". This uses ~1.5 yd of stone instead of 3.5 yd for a full pad. The
   hardware-cloth skirt and apron keep diggers out, so a full pad isn't needed; add one if
   your site is wet.
2. **Skids.** Lay three 4×6×20 PT (ground-contact) skids, 20 ft long, at 0, 4'-9" and
   9'-6" (outer faces flush with the floor edges). Level and square them (diagonals equal).
3. **Floor frame.** Two 2×6×20 PT rim joists, with 2×6 PT joists (9'-9") at 16" o.c.
   between them in joist hangers. Toe-screw or hurricane-tie every joist to every skid.
4. **Rodent skirt.** Before the subfloor goes on, staple and screw ½" hardware cloth
   across the underside of the joists. It stops rats nesting in the floor cavity.
5. **Subfloor.** Seven sheets of ¾" PT plywood, glued and screwed at 6" (edges) and 12"
   (field). Staggered seams.
6. **Walls.** Frame flat on the deck and tilt them up in this order: south (front) and
   north (back) walls at 20 ft, then the east and west end walls fit between them at
   9'-5". Double top plate, lapped at the corners. Opening rough sizes:
   | Opening | Rough opening | Header |
   |---|---|---|
   | People door (east) | 38" × 82½" | 2 × 2×8 + ½" ply |
   | Windows (3 south, 1 west) | 25" × 37", sill at 36" | 2 × 2×8 |
   | Pop door (south, 4 ft from SE corner) | 13" × 17", sill 8" above floor | flat 2×4 |
   | Nest-bay opening (north) | 157" × 14" at 20" above floor | 2 × 2×8, one post at mid-span |
   | Feed slot (east, 4'-9" from the NE corner) | 18" × 5", bottom 10" above the floor | flat 2×4 (between studs) |
   | Water pipe (east, 1'-9" from the NE corner) | 1¼" hole, 14" above the floor | none |
7. **Roof.** Ridge board: 2×8, 22 ft (two 12 ft pieces spliced over a rafter pair).
   Common rafters: 2×6, cut from 8 ft stock. Run 5 ft + 12" overhang, birdsmouth on the
   top plate, 4/12 pitch (18.4°), length about 6'-4" along the top edge. Spacing is
   24" o.c. (11 pairs) plus fly rafters for the 12" gable overhangs.
   **Rafter ties are required:** a 2×6 at every pair at top-plate level, 3 × 16d nails or
   3 × ¼" structural screws per end. They stop the walls spreading, and they carry the
   door actuator and lights. Add hurricane ties at every rafter-to-plate joint.
8. **Roofing.** 2×4 purlins flat at 24" o.c. (4 rows per side). Then 29 ga ribbed steel
   panels (6'-6" long, 1" overhang at the eave), closure strips, a vented ridge cap, and
   rake trim. Fasten with #10 × 1½" gasketed screws in the flat beside the ribs, per the
   manufacturer's pattern.
9. **Siding.** 4 × 9 ft T1-11 panels, installed vertically so they lap the rim joist by
   2". Leave the soffit gap open between rafters at both eaves (screen it in step 11).
   Gable-end triangles come from offcuts. Put corner boards on the outside corners.
10. **Doors and windows.**
    - *People door:* build a Z-braced door from T1-11 on a 2×4 frame, hung on 3 × 8" T-hinges,
      with a keyed hasp outside and a barrel bolt inside. (A prehung steel door is fine too.)
    - *Windows:* ½" hardware cloth fixed with 1×2 battens and screws (not staples). Add
      top-hinged storm shutters made from the T1-11 window cut-outs, propped open in
      summer and closed on the windward side in winter. No extra material to buy.
    - *Pop door:* ½" HDPE (cutting-board stock) or exterior plywood, 14" × 19", running in
      two 24" aluminium U-channels. The actuator mounts above on a 2×6 header block inside
      (see §6).
11. **Screen everything.** Put ½" hardware cloth over the soffit gaps, gable vents and any
    gap > ½". Use 1" fender washers and screws every 4–6", since raccoons pull staples.
12. **Nest bay** (§4), **roosts and poop board** (§5), **service station** (§7).
13. **Paint.** Prime and paint all exterior wood, light colour for summer heat. Use
    exterior latex inside the nest bay and on the poop board for easy cleaning.
14. **Apron.** Dig a trench around the coop perimeter not covered by the run, 6" deep.
    Lay 24" of hardware cloth flat outward from the skirt, pinned with landscape staples,
    then back-fill. (The run has its own apron; see `run-and-fencing.md`.)
15. **Floor finish.** Once the PT plywood is dry (a few weeks, or when water beads rather
    than soaks in), roll on two coats of porch & floor enamel, carried 6" up the walls,
    and caulk the floor-to-wall joint. Then add 8–12" of pine shavings (deep litter).
    This costs about $125 less than sheet vinyl and is just as easy to scrape clean.
16. **Services.** Electrical per `wiring.md`, water per `plumbing.md`, then the automation
    in the order given in the top-level `README.md`.

## 3. Cut list (major framing)

| Member | Size | Qty | Length | Notes |
|---|---|---|---|---|
| Skids | 4×6 PT (GC) | 3 | 20' | Ground-contact rated |
| Rim joists | 2×6 PT | 2 | 20' | |
| Floor joists | 2×6 PT | 16 | 9'-9" | From 10' stock, 16" o.c. |
| Bottom plates | 2×4 PT | 7 | 10' | 60 lf + waste |
| Top plates (double) | 2×4 | 14 | 10' | 120 lf + laps |
| Studs | 2×4 precut | 90 | 92⅝" | Includes kings, jacks, cripples, corners, nest-bay framing |
| Gable studs | 2×4 | 6 | 8' | Cut to fit, 16" o.c. |
| Headers | 2×8 | 5 | 10' | Door, 4 windows, nest bay (doubled) |
| Ridge | 2×8 | 2 | 12' | Spliced over a rafter pair |
| Rafters (incl. fly) | 2×6 | 26 | 8' | 11 pairs + 2 fly pairs |
| Rafter ties | 2×6 | 11 | 10' | Every pair |
| Purlins | 2×4 | 16 | 12' | 8 rows × 22' |
| Roosts | 2×4 | 5 | 9' | Sand smooth, round the edges |
| Roost/poop-board frame | 2×4 | 6 | 10' | Ledger + legs + board frame |
| Ramp | 2×10 | 1 | 6' | Cleats from 1×2 every 6" |
| Service station frame | 2×4 | 10 | 8' | Sill, corner posts, door frames, lid/roof rafters |
| Feed bin | ¾" ext. plywood | 2 sheets | | Sides, back, sloped floor, lid (§7) |

## 4. Nest bay (12 boxes, exterior)

nest bay, lid open

- The bay is 13'-6" long × 14" deep × 14" high (inside) and cantilevers off the north wall,
  sitting on the 2×8 header / sill of the 157" opening plus 3 triangular 2×4 brackets
  underneath. The box floor is **20" above the coop floor**.
- Build it from ½" exterior plywood: floor, back, ends and 11 dividers make 12 boxes of
  about 12" W × 12" H × 14" D. A 4" lip across the front keeps the nesting material in.
- The lid is ¾" plywood with roofing on top, hinged to the wall on a 72" piano hinge (two
  pieces), sloped out 2" to shed rain. Add **two raccoon-proof latches** (a spring-loaded
  gate latch plus a carabiner, or a keyed hasp) and a lid stay.
- Put a nest pad or 2" of shavings in each box, plus a ceramic egg or golf ball to train
  young hens.
- Tier 2 option: a BLE thermometer (`3d-printing/ble_sensor_case.scad`) in the middle box
  reports nest temperature in winter.

## 5. Roosts and poop board

interior cutaway

- Five 2×4 roosts, **wide face up** (so the birds' toes stay covered in winter), each 9'
  long spanning the full interior width at the west end. They sit on 2×4 ledgers screwed
  to the north and south walls, and lift out for cleaning.
- Height 36–40", **13" apart**, all at the same height. Equal heights stop pecking-order
  fights. The first bar is at least 12" from the west wall.
- Poop board: two sheets of ¾" plywood (painted) on a 2×4 frame at **24"** under the whole
  roost area (≈ 9 × 6 ft), edged with a 1×2 lip. Cover it with PDZ or sand and scrape
  daily or weekly. The birds still get the floor space under it.
- The PIR sensor (`3d-printing/pir_mount.scad`) mounts high on the east face of the roost
  area, looking west, so it can see predators in the roost zone at night.

## 6. Pop door and actuator

- The opening is 12" W × 16" H, with its sill 8" above the floor. The door leaf is 14" × 19"
  of ½" HDPE, so it doesn't swell. It runs in two ¾" aluminium U-channels that extend 18"
  above the opening.
- The **12 V linear actuator (18" stroke, ≥ 225 N / 50 lb, IP54+, built-in limit
  switches)** mounts vertically above the opening. Its base clevis bolts to a 2×6 block
  on the rafter tie, and the rod clevis bolts to a small aluminium angle on the top of
  the door leaf. The worm gear holds the door shut, so a raccoon can't lift it.
- Reed switches (`3d-printing/reed_switch_bracket.scad`) go on the U-channel at the fully
  closed and fully open positions, with magnets on the leaf. Adjust the slotted brackets
  until each one trips at the end of travel (watch the entity in HA or the web UI).
- The ramp is a 2×10 × 6 ft board with 1×2 cleats every 6", at ≤ 35°, into the run.
- **Tier 1 without the actuator:** use the same guillotine door with a rope over a pulley
  to a cleat beside the people door, and close it by hand at dusk.
- The door closes at **civil dusk** (sun −6°), by which time the flock has gone in on its
  own. Once, after installing, check at dusk with a headcount. HA also alerts you if the
  door is still open 30 minutes after that.

## 7. Exterior feed & water service station

service station, doors open

Feed and water are both refilled **from outside the coop**, so there's no walking through
litter with feed bags and buckets, nothing to spill inside, and no need to open the coop
at all on a normal day.

- **Station:** a lean-to cabinet on the north end of the east wall, 5 ft wide × 30" deep ×
  6 ft tall. It stands on 4 concrete blocks, framed in 2×4 and sided with T1-11 to match the
  coop, with a steel lean-to roof. There are two side-hinged doors on the east face with
  **raccoon-proof latches** (spring latch + carabiner), or a padlock. Put 1" rigid foam on
  the drum side and roof. Screen any gaps with ½" hardware cloth to keep out rodents and
  wild birds.
- **Feed bin (left, ~350 lb / 7 bags ≈ 3–4 weeks):** a ¾" plywood box 24" wide × 26" deep ×
  42" tall with a hinged lid. Its **floor slopes at 45°** down toward the coop wall and ends
  at an 18" × 5" slot through the wall, 10" above the coop floor. An aluminium **slide gate**
  on the outside of the slot sets the flow and shuts it off for cleaning.
  - Inside, a 48" galvanized **trough on a 10" stand** sits under the slot. Feed runs down as
    the hens eat it, which is the classic gravity-feeder principle, just at a larger scale.
    A wire grill across the trough cuts billing waste.
  - Fill it to about 3 weeks' worth at a time so the feed stays fresh. In humid climates,
    seal the bin seams with caulk and gasket the lid (closed-cell foam tape).
  - The JSN-SR04T ultrasonic sensor mounts in the bin lid
    (`3d-printing/ultrasonic_lid_mount.scad`), so HA shows the feed level and alerts you
    when it's low.
- **Water (right):** the 30 gal drum sits on an 18" block stand. The supply hose, vacuum
  breaker, regulator, filter and 12 V solenoid all live in the station, so no pressurised
  water ever enters the coop. The outlet runs as ¾" PVC **through the wall at 14"** to the
  nipple line inside, and the overflow drains outside, away from the station. Fill it by hose
  through the lid (Tier 1), or let the floats and solenoid do it (Tier 2). See `plumbing.md`.
- **Winter:** the insulated drum side plus the de-icer (relay 2) keep the drum liquid. Put
  self-regulating heat cable under foam on the short exposed pipe run and the indoor nipple
  line. In hard-freeze climates, a heated nipple bucket inside is the fallback.

interior feed and water

## 8. Ventilation and insulation

- **Ventilate, don't seal.** Ammonia and moisture are a bigger winter risk than cold. The
  open eave soffits (2 × 20 ft × ~4" net) plus the ridge vent give continuous high-level
  airflow. Windows add summer cross-flow. Close the shutters on the windward side in winter
  but **never block the soffit or ridge vents**.
- The 12 V exhaust fan (J14) mounts in the east gable vent, blowing out. The firmware runs
  it above 27 °C or 80 % RH.
- Don't insulate the walls. Chickens handle cold well when they're dry and out of drafts.
  In very cold climates, add 1" rigid foam under the roof steel, over the purlins, to stop
  condensation dripping on the roosts.

## 9. Interior layout (see floor plan)

| Zone | Contents |
|---|---|
| West 6 ft | Roosts and poop board (sleeping) |
| North wall | 12 nest-box openings at 20" |
| East wall, north end | Feed trough under the wall slot (fed from the exterior bin). Mains box and controller box above it at 5 ft, with short cable runs through the wall to the station sensors |
| Centre | Nipple/cup line at 12–14", piped through the east wall from the exterior drum |
| East wall, south end | People door |
| Ceiling | 2 LED jelly-jar lights, PIR over the roosts, BME280 radiation shield on the north wall |

Keep feed and water **out from under the roosts**, and give at least 3 ft of clear floor
in front of the nest boxes.

## 10. Maintenance calendar

| When | Task |
|---|---|
| Daily | Collect eggs, glance at the HA dashboard, scrape the poop board (or weekly with PDZ) |
| Weekly | Check the feed level (HA) and water nipples. Check the door runs smoothly |
| Every 3–4 weeks | Refill the feed bin from outside (about 7 bags). Brush out any caked feed at the slot |
| Monthly | Stir or turn the deep litter, clean the nipple line filter, check latches and hardware cloth |
| Spring/fall | Muck out the deep litter (compost it), inspect the roof and siding, check the apron, re-check the door reed positions |
| Before winter | Drain the supply hose, test the de-icer / heat cable, close the windward shutters, check the station insulation and door seals, press the GFCI test button |

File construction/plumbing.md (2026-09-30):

# Water: Spigot to Drinkers

plumbing

Demand: 50 hens drink about **6 gal/day** in mild weather and up to **12 gal/day** in
heat. A **30 gal** food-grade drum holds 2.5–5 days, which is enough buffer that the
automation is a convenience rather than a single point of failure.

The drum and all pressurised plumbing live in the **exterior feed & water service station**
on the east wall (`coop-build-plan.md` §7). You can fill and service it from outside, and
the only water that enters the coop is the unpressurised gravity line to the drinkers.

service station

## Supply chain (from the house spigot)

| # | Part | Why |
|---|---|---|
| 1 | Existing hose spigot (frost-free if you have one) | Source |
| 2 | **Hose-bib vacuum breaker** (ASSE 1011) | Required backflow protection: stops coop water siphoning back into the house supply |
| 3 | Brass Y-valve with shut-offs | Keeps one port for your garden hose |
| 4 | **Pressure regulator, 25 psi**, ¾" GHT | Protects the solenoid, float and fittings. Low pressure is also gentler if a float sticks |
| 5 | Inline screen filter (40–100 mesh) | Sediment clogs nipples and pilot valves |
| 6 | **Drinking-water-safe hose** (lead-free, NSF-61) | Garden hose leaches lead/BPA. Bury it 12" in a trench, or run it in foam pipe insulation, up to the station |
| 7 | **12 V normally-closed solenoid valve**, ½" brass, pilot-operated (min. about 3 psi), mounted inside the station | Tier 2. Fails **closed** on power or controller failure |
| 8 | Drum inlet: ½" bulkhead fitting in the lid or high on the side | |
| 9 | Overflow: ¾" bulkhead 2" below the rim, PVC through the station floor, draining **away from the station** | If a float or valve ever sticks, the water goes onto the ground outside, never into the litter |
| 10 | Outlet: ¾" bulkhead near the bottom, then a ball valve, then ¾" PVC **through the coop wall at 14"** to the drinker line | The only pipe that enters the coop, and it's unpressurised |

## Drinkers (inside the coop)

- The ¾" PVC line enters through the east wall and runs west, then turns to run through
  the middle of the floor (see the floor plan). It carries **10+ horizontal nipples**
  (1 per 5–6 birds) or **cup drinkers** (1 cup per 8–10 birds) at the birds' head height,
  about 12–14" for standard layers. Horizontal nipples drip less than vertical ones and
  suit a gravity drum.
- The drum sits on an **18" block stand** in the station. Its bottom is then about 30"
  above grade, and the nipple line is about 26" above grade (floor ≈ 12" + 14"), so there's
  enough head (≈ 0.3–1 psi) to feed the line. Keep the line level, or falling slightly
  away from the drum.
- Screen the drum's lid vent (mosquitoes) and keep the drum opaque or painted (algae).

## Level sensing (Tier 2)

| Sensor | Position | Terminal |
|---|---|---|
| LOW float | ~⅓ full | J7 WATER_LOW |
| HIGH float | ~2" below the overflow | J7 WATER_HIGH |
| DS18B20 probe | Hanging at mid-depth, away from the de-icer | J8 ONEWIRE |

Use vertical side-mount or top-mount reed float switches (PP body, food-safe). Install
them so the **contact closes when the water is BELOW the float**. With that convention a
broken wire reads "not below", so the firmware never opens the valve on a dead sensor.
The sensor cables run through a sealed gland in the station wall straight to the
controller, which sits on the other side of the same wall, inside the coop.

### Firmware behaviour (`firmware/packages/water.yaml`)

- Water drops below LOW: the valve opens (if `Water Auto Fill` is on and there's no lockout).
- The valve closes when the level reaches HIGH.
- If HIGH isn't reached within `Water Max Fill Time` (default 10 min), the valve closes and
  **Water Fill Lockout** latches, and HA notifies you. Likely causes are a leak, supply
  turned off, a frozen hose or a stuck float. Fix the cause, then press
  `Water Fill Lockout Reset`.
- A separate watchdog closes the valve after max-fill + 1 minute, even if you opened it by hand.
- **No filling when the water is at or below 1 °C.** The hose is probably frozen.
- `Water Float Fault` fires if LOW says "below" while HIGH says "above", which is
  physically impossible.

## Winter / freeze protection

The drum is outdoors in a cabinet, so plan for this:

1. **Station insulation:** line the drum side and the roof of the station with 1" rigid
   foam, and keep the doors closed (weather-stripped). The drum's thermal mass plus the
   de-icer does the rest.
2. **Drum:** put a **plastic-safe, thermostatic** floating or submersible de-icer (250 W)
   on **relay 2** (J6 HEAT). The firmware turns it on below 3 °C water temperature and off
   above 6 °C. If the probe fails, it falls back to coop air below 2 °C.
3. **Pipe and drinker line:** wrap self-regulating heat cable (≈ 3 W/ft) on the short
   exposed pipe between the drum and the wall and along the indoor nipple line, under foam
   insulation. Plug it into the same relay-2 outlet with a rated splitter (total well under
   the 6 A relay and receptacle ratings).
4. **Supply hose:** the easiest approach is to disconnect and drain it when nights go below
   freezing, and fill the drum by hand through the lid every 3–4 days. It's right there
   behind the station doors. The alternative is a heated drinking-water hose on a separate
   GFCI outlet.
5. **Low-tech fallback:** two heated 3 gal poultry waterers on the GFCI receptacle inside
   the coop.

## Tier 1 (no electronics)

Skip items 7–8 and the floats. Either fill the drum by hose through the lid every 3–4 days
(open the station, fill, close; no need to enter the coop), or fit a **mechanical
stock-tank float valve** fed through the same vacuum breaker, regulator and filter. That
gives you automatic filling with no electricity at all. Tier 2 then adds the solenoid in
front of it as a **leak-protection master valve** controlled by the floats.

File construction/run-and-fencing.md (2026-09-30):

# Secure Run, Fencing and Free-Range Plan

site plan

overview

The flock **free-ranges most of the day**. The run is for bad-weather days, for keeping
the birds in while you're away, and for the first two weeks after moving in (to "home"
them to the coop). The ranging area is protected by portable electric netting.

## 1. Secure run: 20 × 25 ft (500 sq ft, 10 sq ft/bird)

Attached to the south wall of the coop so the pop door opens straight into it.

| Element | Spec |
|---|---|
| Posts | 4×4×10 PT, 12 of them, at ≤ 8 ft o.c., set 30" deep on 4" of gravel (concrete optional). 6'-6" clear height |
| Top rail | 2×4 PT between the post tops. Mid-rail at 36" |
| Lower wall (0–36") | **½" 19-ga hardware cloth**, screwed with fender washers to the posts and rails. Rats, weasels and raccoon hands can't pass it |
| Upper wall (36"–6'6") | 2 × 4" 14-ga welded wire (keeps out dogs, coyotes and foxes above ground level) |
| Apron | 24" of hardware cloth laid flat **outward** at the base, pinned and buried 2–4" (or covered with pavers). Diggers hit the mesh at the fence line and give up |
| Roof | Heavy knotted aviary netting (2" mesh) on 2×4 purlins at 4 ft o.c., plus a **12 × 16 ft HDPE shade sail** over the half nearest the coop for summer shade. The coop itself is the rain shelter. In snow country, take the netting and sail down in winter (or, if budget allows, steel-roof that half: about $400 more) |
| Gates | 36" walk-in gate (east side) with **two** latches, one a carabiner. Three 18 × 24" "range gates" (east, south and west sides), one into each paddock, as guillotine doors on U-channel |
| Floor | Leave soil. Add 4" of wood chips or sand in wet areas. Keep a dust-bath corner (sand + wood ash) under the shade sail |

**Raccoons open simple latches.** Use spring-loaded gate latches plus a carabiner or snap,
everywhere.

## 2. Free-range paddocks (electric poultry netting)

- Use three paddocks around the run (A east, B south, C west). **One 164 ft roll of 48"
  electric poultry netting is moved between them.** That's about 0.1 acre per setting, and
  about 0.3 acre in rotation for 50 birds. Moving a roll takes about 15 minutes. Buy a second
  or third roll later only if you want paddocks standing ready (about $215 each).
- Rotate every **2–4 weeks**, or sooner if the ground goes bare, so the grass recovers
  and parasites break their cycle.
- Energizer: a **solar poultry netting energizer (≥ 0.25 J)** with a 3 ft ground rod,
  aiming for ≥ 4,000 V on the net. Check it with a fence tester weekly. Mow a 12" strip
  under the net so grass doesn't short it.
- Netting stops dogs, foxes, coyotes and raccoons in daylight. **It doesn't stop hawks.**
  Leave shrubs, a pallet lean-to or shade cloth in each paddock for cover. A rooster, or
  a guardian dog if appropriate for you, adds protection.
- **Routine:** open the range gate after the morning egg collection. The birds come back
  to the coop on their own at dusk, and the auto door closes behind them at civil dusk.
  Close the range gate at dusk (Tier 1), or fit a second actuator on J13/IO5 later (upgrade).

## 3. Coop perimeter

- The coop's own hardware-cloth skirt and apron (see `coop-build-plan.md` §2) protect the
  sides not enclosed by the run.
- Keep a 3 ft mown/gravel strip around the coop and run. Predators avoid open ground,
  and you'll see dig attempts early.

## 4. Materials (run + range)

| Item | Qty |
|---|---|
| 4×4×10 PT posts | 12 |
| 2×4×10 PT rails | 16 |
| 2×4×12 (roof purlins) | 7 |
| ½" 19-ga hardware cloth, 48" × 100 ft | 1 (lower wall) |
| ½" 19-ga hardware cloth, 24" × 100 ft | 2 (run apron + coop apron) |
| 2 × 4" 14-ga welded wire, 48" × 100 ft | 1 |
| Aviary netting, 25 × 25 ft (2" knotted) | 1 |
| Shade sail, 12 × 16 ft HDPE + ties | 1 |
| Walk gate kit + 2 latches, carabiners | 1 set |
| Electric poultry netting, 48" × 164 ft | 1 (moved between paddocks) |
| Solar netting energizer + ground rod + tester | 1 |
| Fender washers (1") + 1¼" exterior screws | 1,000 |
| Gravel for post holes | 1 yd |

Prices are in `docs/parts-list.md`.

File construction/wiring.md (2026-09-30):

# Electrical Wiring

> **120 V AC SAFETY: READ FIRST.** Wet, dusty, ammonia-laden outdoor buildings are the
> harshest place you can put mains wiring. **Have a licensed electrician install and
> inspect everything on the 120 V side** (feeder, breaker, GFCI, mains enclosure, relay load
> wiring, lights, receptacles) to your local code (NEC Articles 210, 225, 300, 547 in
> the US). Every 120 V circuit to the coop **must be GFCI protected**. This document
> describes the intended design so you and your electrician share one plan. It is **not**
> a substitute for them.

wiring

## 1. Architecture

There are two separate enclosures, and they are never combined:

| Enclosure | Contents | Voltage |
|---|---|---|
| **Mains box.** NEMA 4X / IP65 polycarbonate or fibreglass, DIN rail, about 300 × 250 × 150 mm | 2-pole 20 A DIN breaker, GFCI receptacle (unless GFCI at the panel), Mean Well **HDR-100-12N** 12 V PSU, **relay 1** (lights), **relay 2** (de-icer / heat cable), ground bar | 120 V AC in, 12 V DC out |
| **Controller box.** IP65 ABS, about 250 × 200 × 100 mm | Coop Controller PCB on the printed back-plate, cable glands on the bottom face only, door push-button + status LED on the lid | 12 V DC and below |

Mount both boxes on the east wall inside the coop, at the north end, 5 ft up, out of peck
and splash range. That puts them directly behind the exterior feed & water station, so
the float, probe, valve and feed-level cables are only a few feet long. They pass through
the wall in a sealed gland.
Run all cables in PVC conduit or sealed flexible conduit (rodents chew cable).

## 2. Feeder to the coop (electrician)

- Use a **dedicated 20 A circuit** from the house panel with a **GFCI breaker** (or a
  20 A breaker plus a GFCI device as the first thing in the coop).
- The cable is **UF-B 12/2 with ground**, direct burial, or THWN in PVC conduit. Burial
  depth for a residential 120 V, ≤ 20 A, GFCI-protected branch circuit is **12"**
  (NEC 300.5, Table, column 4). Deeper is fine. Use conduit wherever it's exposed above
  grade.
- Voltage drop: 12 AWG is fine up to about 100 ft at the ~6 A this coop actually draws.
  Go to 10 AWG beyond that.
- Enter the mains box from the bottom through a listed fitting. Put a disconnect inside
  the coop (the DIN breaker) so you can isolate the coop locally.

## 3. Mains box wiring (electrician)

| From | To | Conductor |
|---|---|---|
| Feeder L / N / G | 2-pole DIN breaker L / N, ground bar | 12 AWG |
| Breaker L / N | GFCI receptacle line side | 12 AWG |
| Breaker L / N | PSU L / N, PSU ⏚ to ground bar | 14 AWG |
| Breaker **L** | Relay 1 COM → relay 1 NO → **light fixture hot** | 14 AWG |
| Breaker **L** | Relay 2 COM → relay 2 NO → **de-icer receptacle hot** (single weatherproof outlet in the station) | 14 AWG |
| Breaker N | lights neutral, de-icer receptacle neutral | 14 / 12 AWG |
| Ground bar | every fixture, receptacle, metal box, PSU ⏚ | green / bare |

- **The relays only switch the HOT conductor.** Neutral and ground are never switched.
- **Default: DIN-rail relay modules** with a 12 V DC coil, 6 A / 250 V AC contacts, a status
  LED and a **built-in coil suppression diode** (e.g. Finder 38.51.7.012.0050 or equivalent,
  about $16 each). They cost about a third as much as genuine SSRs, dissipate no heat, and
  can't be counterfeit-shorted like cheap "Fotek" SSRs. Two 9 W LED bulbs and a 250 W
  de-icer + 36 W heat cable (≈ 2.4 A) are well inside the rating. **Keep the relay-2 load
  ≤ 500 W.** If your module has no built-in diode, fit a 1N4007 across A1/A2 (cathode
  to A1) to protect the PCB's 2N7000 driver.
- Alternative: zero-cross SSRs (input 3–32 V DC, ≥ 10 A / ≥ 25 A output). Use genuine
  Crydom/Omron/Carlo Gavazzi parts only. The PCB drives either type unchanged.
- Relay 2 failing welded or open is fail-safe either way, because the de-icer has its own
  thermostat.
- The de-icer itself must be thermostatically controlled. The controller is an extra
  layer, not the only protection against overheating.

## 4. 12 V DC from the PSU to the controller

| From | To | Cable |
|---|---|---|
| PSU +V | Controller **J1 VIN_RAW** | 16/2 outdoor, in conduit between boxes |
| PSU −V | Controller **J1 GND** | 〃 |

The PCB has its own 5 A fuse, reverse-polarity diode and TVS. Set the PSU trim pot to
12.5 V if you add the backup battery (optional, see below).

### Optional battery backup (Tier 2+)

A 12 V 7 Ah SLA battery on a float charger, diode-ORed (Schottky, 10 A) with the PSU
output, keeps the door, sensors and WiFi running through an outage: about 0.25 A average,
so over 24 h. The firmware reports `12V Supply Voltage` and raises `12V Supply Low` below
11.5 V.

## 5. Controller terminals: field wiring

This comes from `hardware/pinmap.yaml`, so it always matches the PCB and firmware.

| Terminal | Pins | Connects to | Cable / notes |
|---|---|---|---|
| **J1 PWR_IN** | VIN_RAW, GND | PSU +V / −V | 16/2 |
| **J2 ACTUATOR** | M+, M− | Linear actuator red (M+), black (M−) | 16/2 outdoor. If the door moves the wrong way, swap the two leads |
| **J3 DOOR_SW** | DOOR_CLOSED_SW, DOOR_OPEN_SW, GND | Reed switch at the closed position, reed switch at the open position, common | 18/5 sprinkler wire (direct-burial rated, cheap, colour-coded) |
| **J4 VALVE** | +12V, VALVE− | Solenoid valve coil (either way round) | 18/2 |
| **J5 FEEDER** | +12V, FEEDER− | **Optional** metered-auger gear motor | Unused with the default gravity feed bin. 16/2 if fitted |
| **J6 SSR_OUT** | +12V, LIGHT_SSR−, +12V, HEAT_SSR− | Relay 1 **A1** / **A2**, relay 2 **A1** / **A2** (or SSR + / −) | 18/4. The only cable between the two boxes besides J1 |
| **J7 WATER_LVL** | WATER_LOW, WATER_HIGH, GND | Low float, high float, common | 18/5 sprinkler wire. Mount the floats so the contact **closes when the water is below the float** |
| **J8 ONEWIRE** | +3V3, ONEWIRE, GND | DS18B20 probe red, yellow, black | The probe's own lead, extended with Cat5e if needed (≤ 10 m) |
| **J9 I2C** | +3V3, I2C_SDA, I2C_SCL, GND | BME280 and BH1750 boards (in parallel) | Cat5e: SDA+GND on one pair, SCL+3V3 on another. **Keep under 2 m** |
| **J10 PIR** | +5V, PIR, GND | HC-SR501 VCC, OUT, GND | 18/3 or Cat5e. Set the PIR jumper to "H" (retrigger) |
| **J11 ULTRASONIC** | +5V, US_TRIG, US_ECHO_5V, GND | JSN-SR04T 5V, Trig, Echo, GND | Cat5e, ≤ 3 m |
| **J12 PANEL** | DOOR_BTN, GND, LED_PANEL, GND | Lid push-button (NO), status LED (anode on LED_PANEL; 330 Ω is on the PCB) | Short leads inside the box |
| **J13 EXPANSION** | +3V3, GND, +5V, SDA, SCL, IO5 | Future sensors (ammonia, second BME280…) | 2.54 mm header |
| **J14 FAN** | +12V, FAN− | 12 V exhaust fan / bilge blower | 18/2 |

### Load current budget (12 V)

| Load | Typical | When |
|---|---|---|
| Controller + ESP32 + sensors | 0.25 A | always |
| Door actuator | 2–3 A (stall ≤ 5 A, stopped by internal limits) | about 25 s, twice a day |
| Optional feeder auger | 1–2 A | 20 s, twice a day if fitted. **The firmware won't run it while the door is moving** |
| Solenoid valve | 0.5 A | while filling |
| Exhaust fan | 0.3–1 A | hot/humid periods |
| Relay coils | 2 × ~20 mA (SSR inputs ≈ 10 mA) | |

The worst realistic simultaneous load is about 4.5 A, within the 7.5 A PSU and the
PCB's 5 A slow-blow fuse.

## 6. Installation practice

- Seal every cable entry: glands on the bottom faces, with a **drip loop** below each.
- Keep 12 V and 120 V in separate conduits, or at least 12" apart where they run in parallel.
- Use ferrules on stranded wire in the screw terminals. Label both ends of every cable
  with its terminal (e.g. "J7-1 WATER_LOW").
- Fix sensor cables along the rafters or ties, never where birds can perch on them or
  peck them.
- **Commissioning:** with the PCB powered but the field devices disconnected, toggle each
  output from the ESPHome web UI and confirm it at the terminal with a meter. Then
  connect the devices one at a time.
- Test the GFCI monthly with its TEST button.

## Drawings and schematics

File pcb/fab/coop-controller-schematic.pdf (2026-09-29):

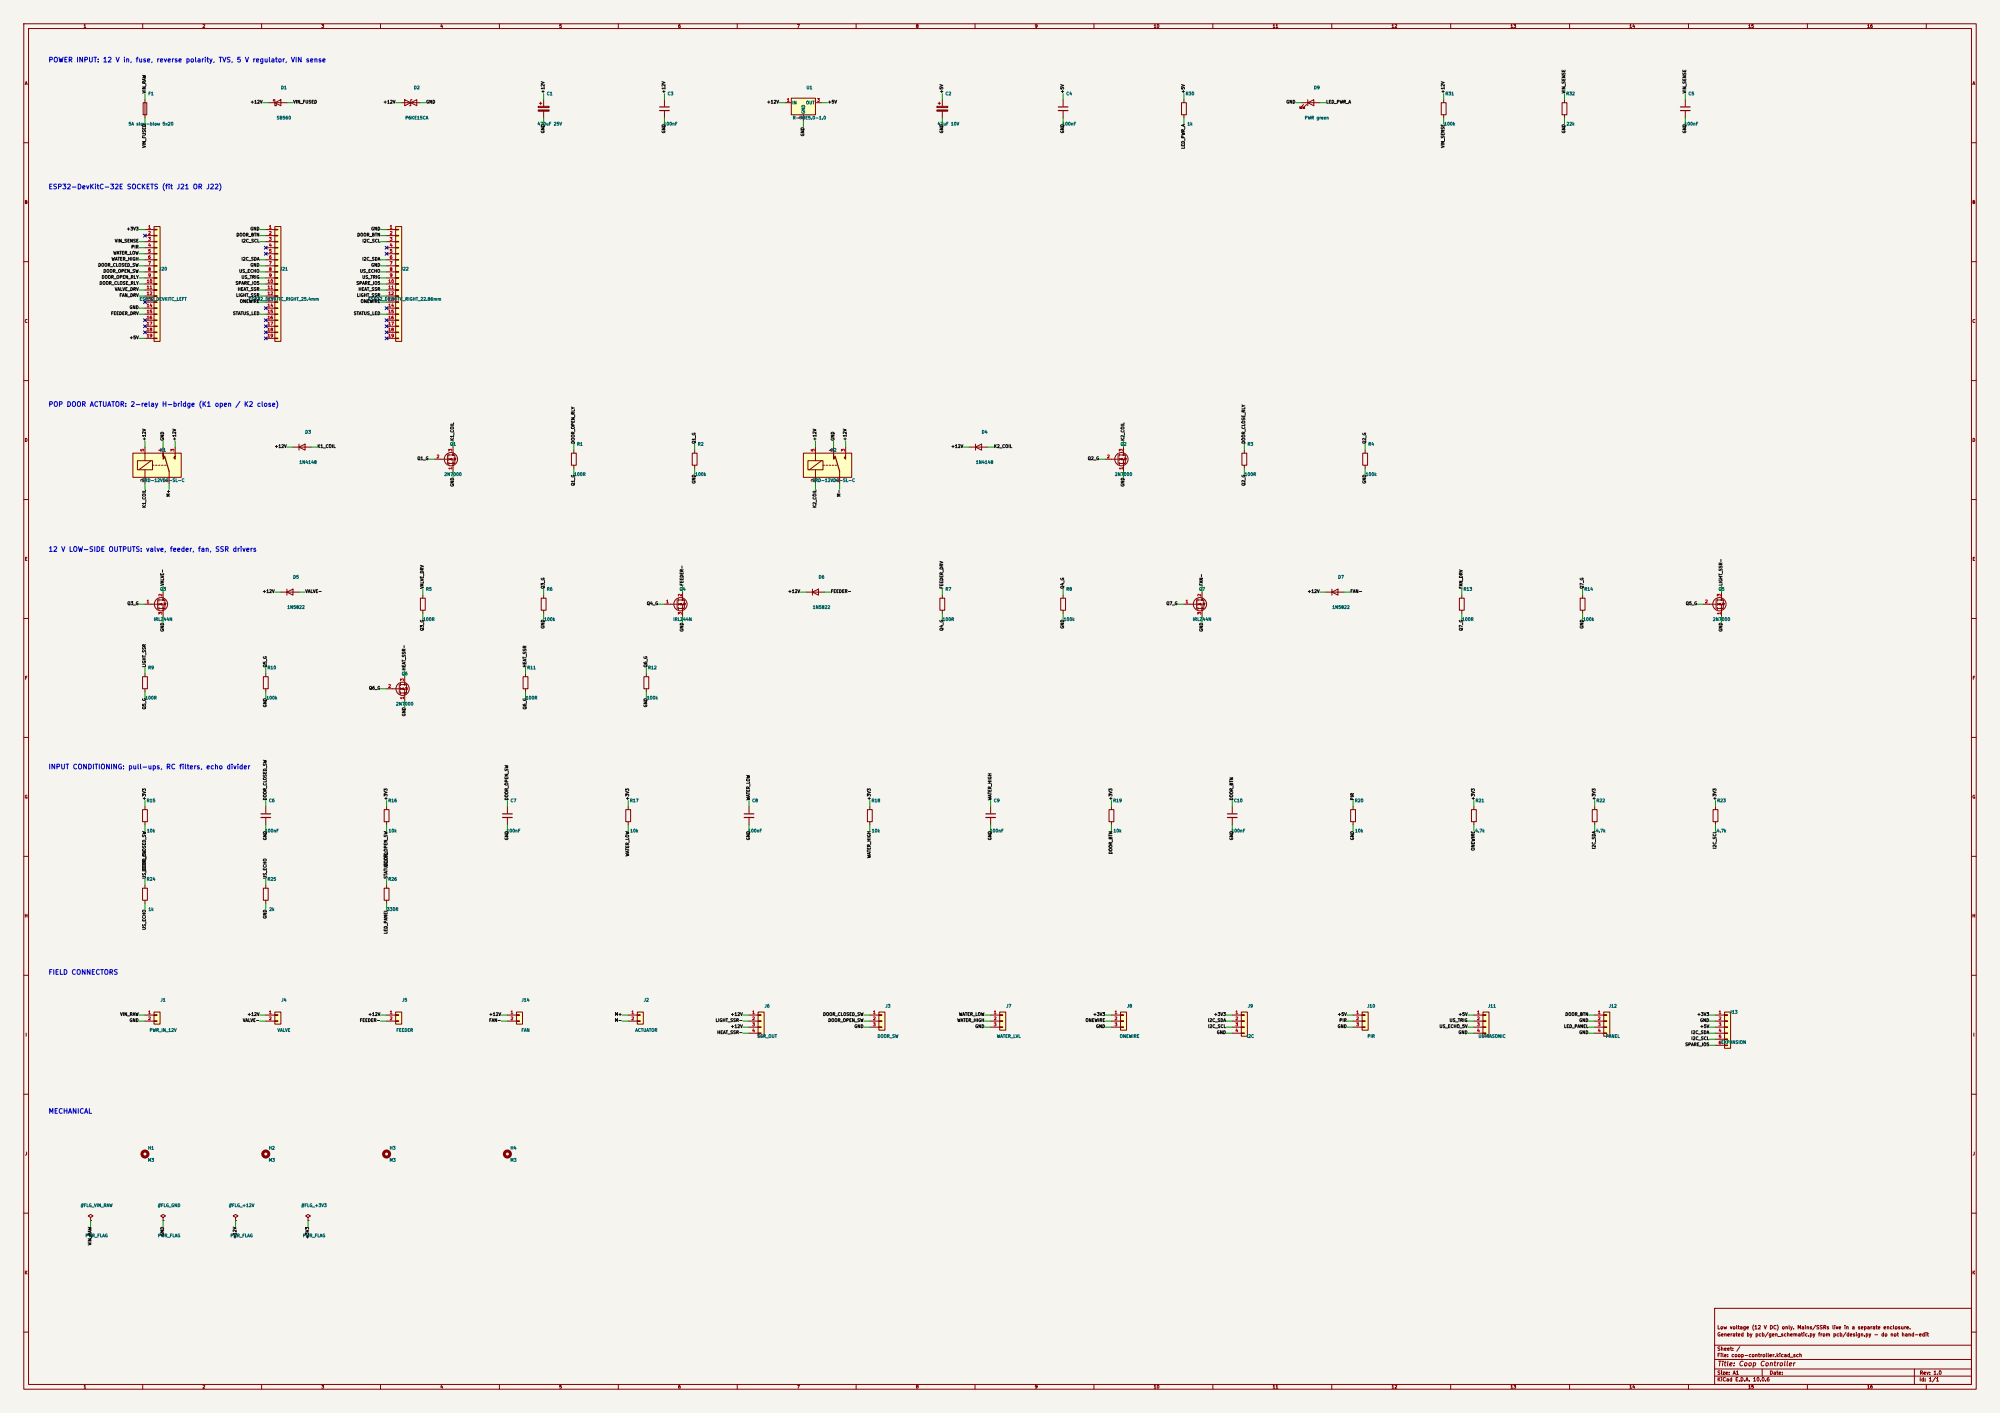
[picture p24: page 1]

POWER INPUT: 12 V in, fuse, reverse polarity, TVS, 5 V regulator, VIN sense

ESP32-DevKitC-32E SOCKETS (fit J21 OR J22)

POP DOOR ACTUATOR: 2-relay H-bridge (K1 open / K2 close)

12 V LOW-SIDE OUTPUTS: valve, feeder, fan, SSR drivers

INPUT CONDITIONING: pull-ups, RC filters, echo divider

Low voltage (12 V DC) only. Mains/SSRs live in a separate enclosure.
Generated by pcb/gen_schematic.py from pcb/design.py - do not hand-edit

Size: A1 | Rev: 1.0
KiCad E.D.A. 10.0.6 | Id: 1/1

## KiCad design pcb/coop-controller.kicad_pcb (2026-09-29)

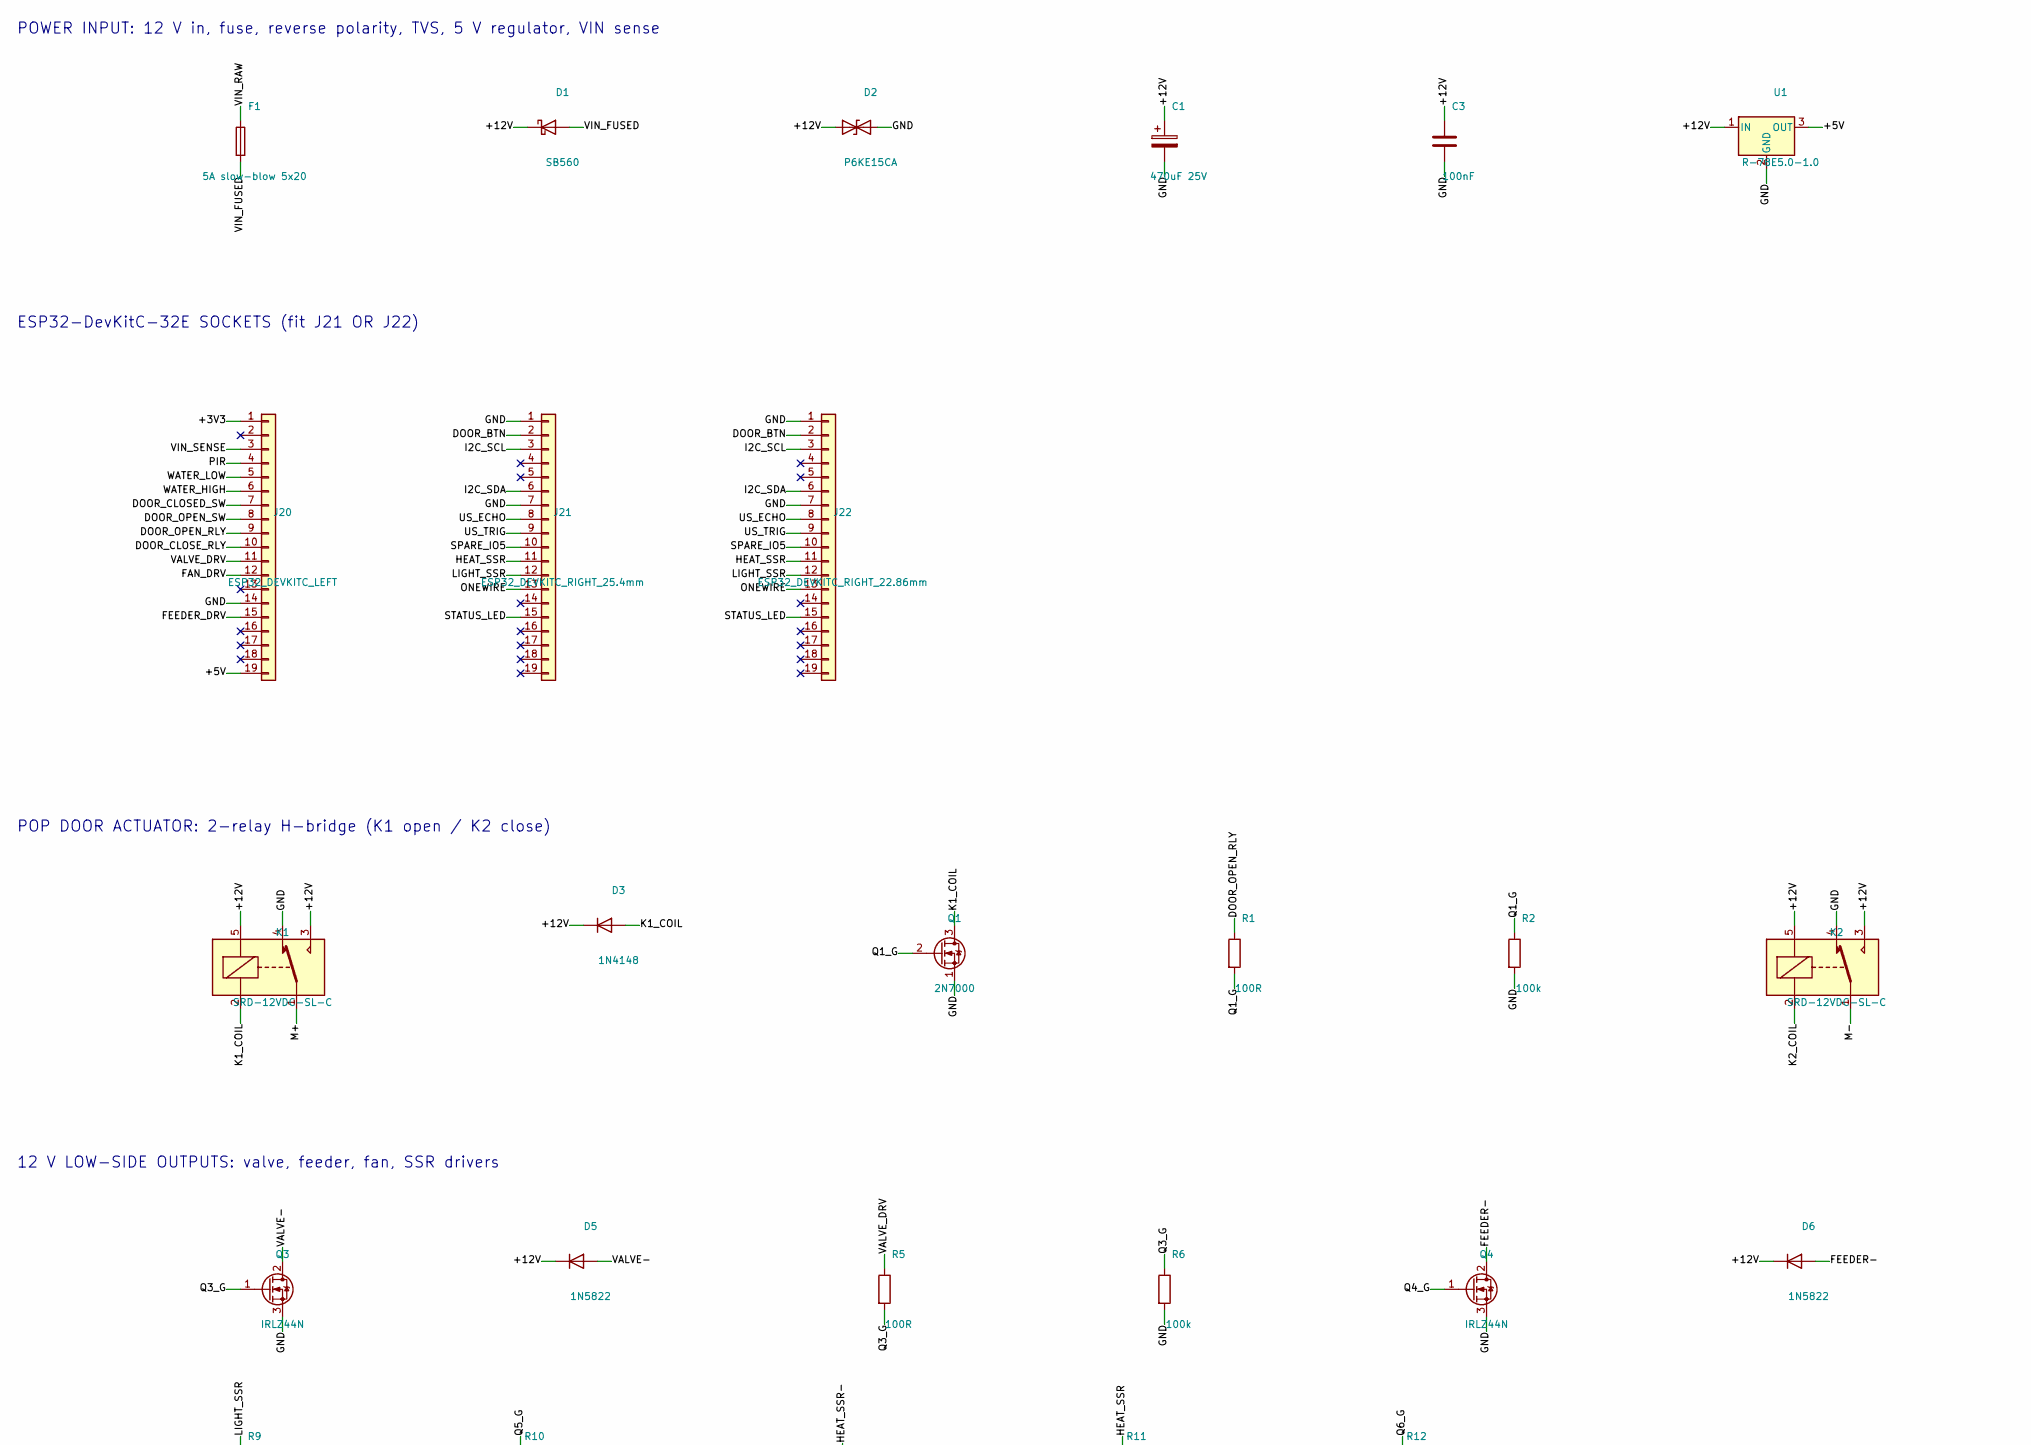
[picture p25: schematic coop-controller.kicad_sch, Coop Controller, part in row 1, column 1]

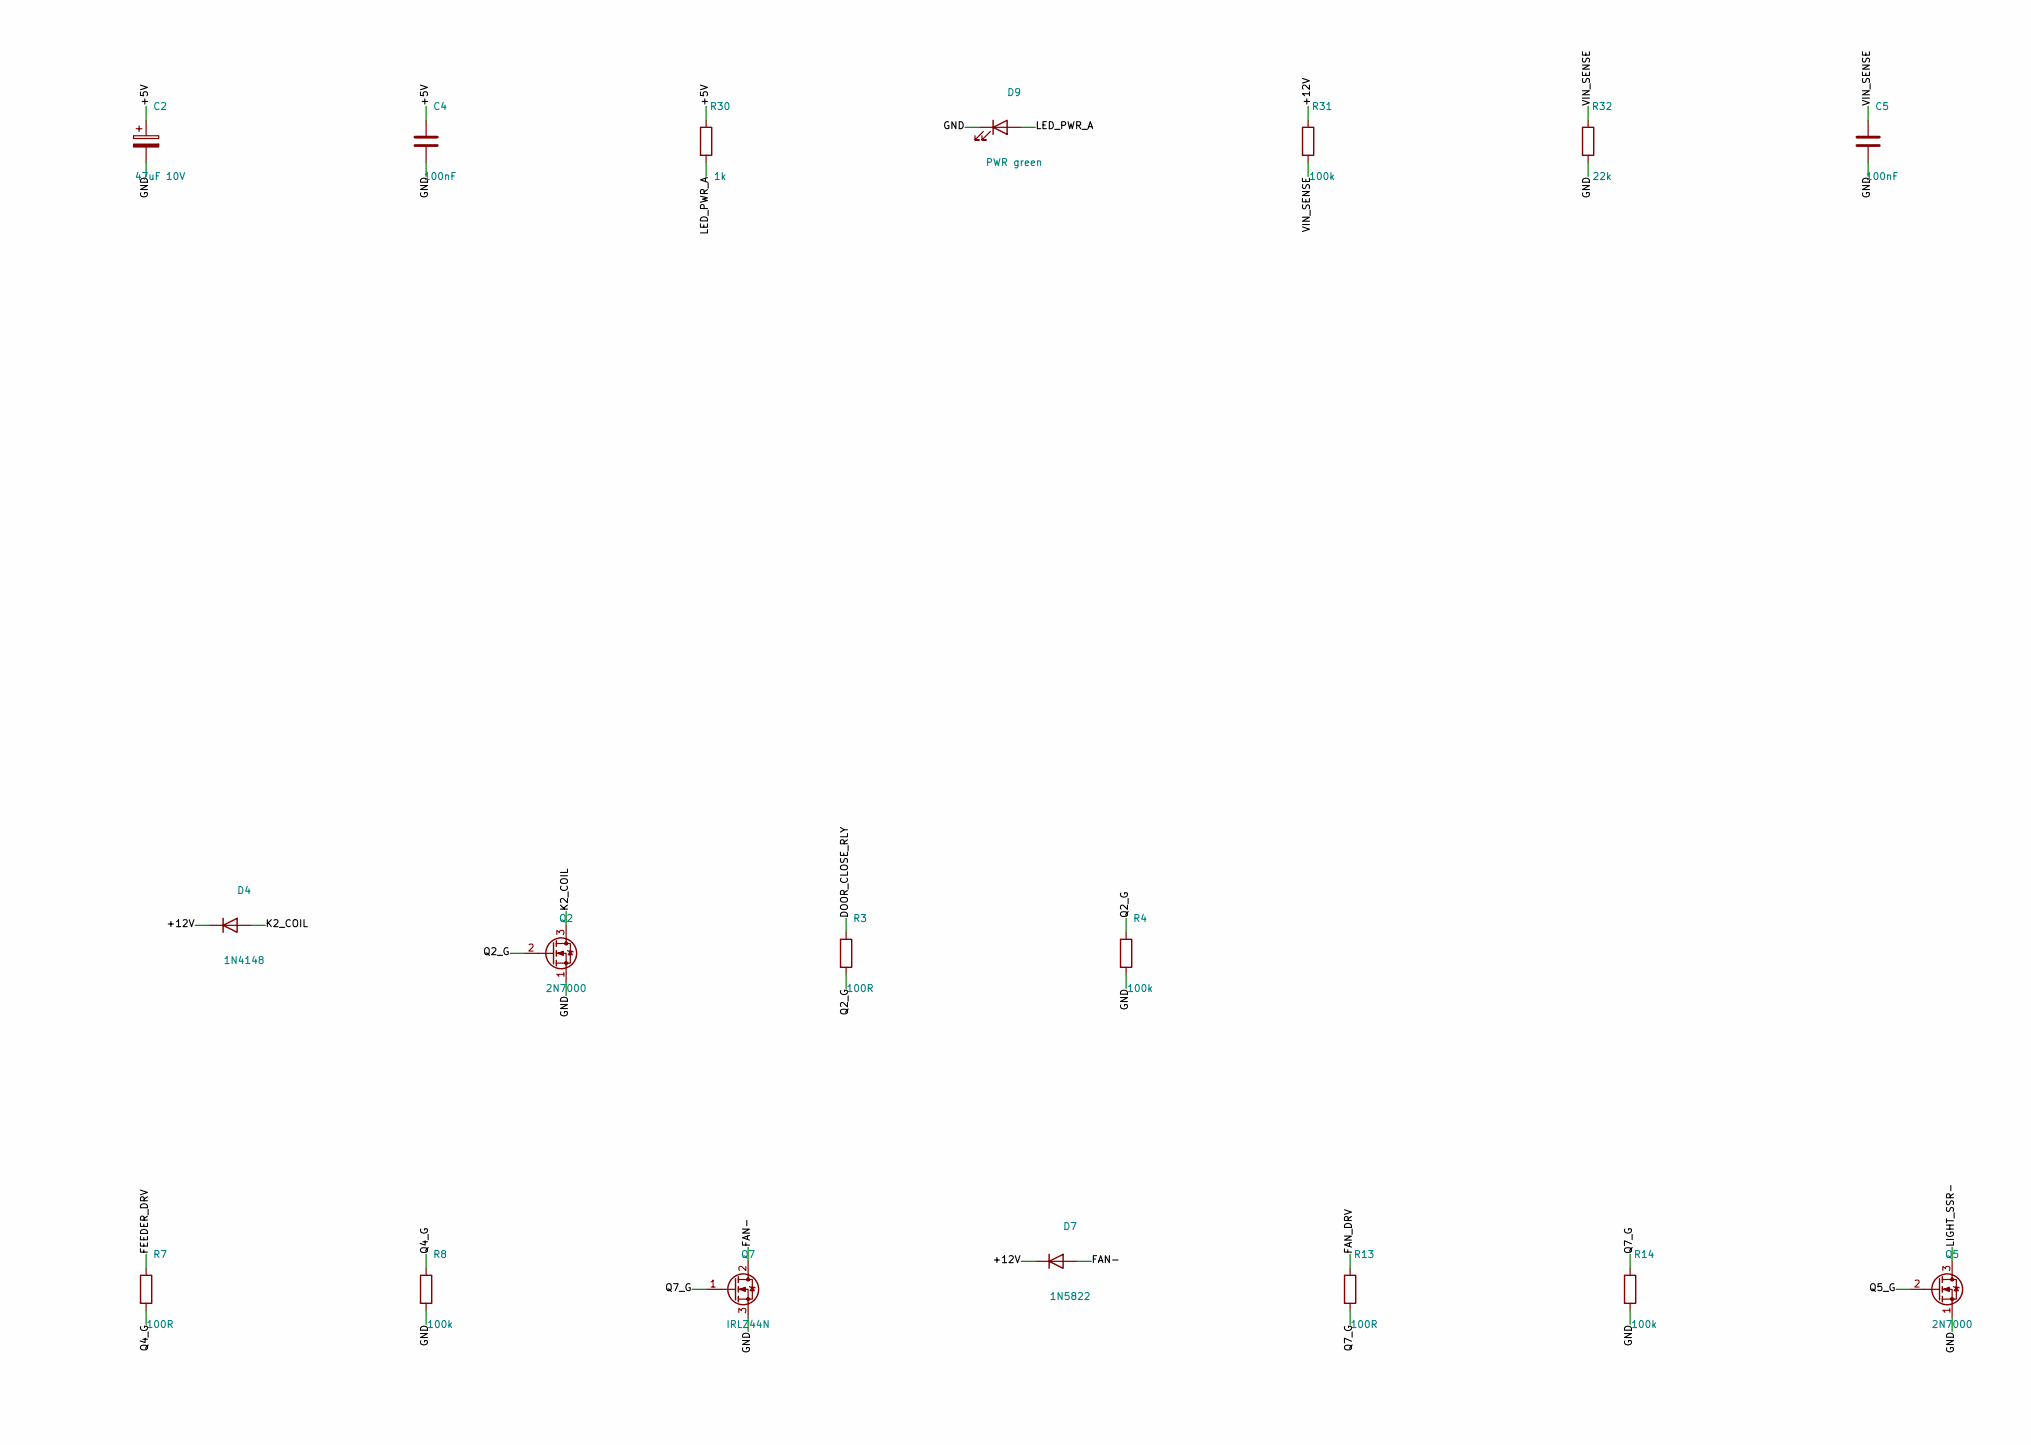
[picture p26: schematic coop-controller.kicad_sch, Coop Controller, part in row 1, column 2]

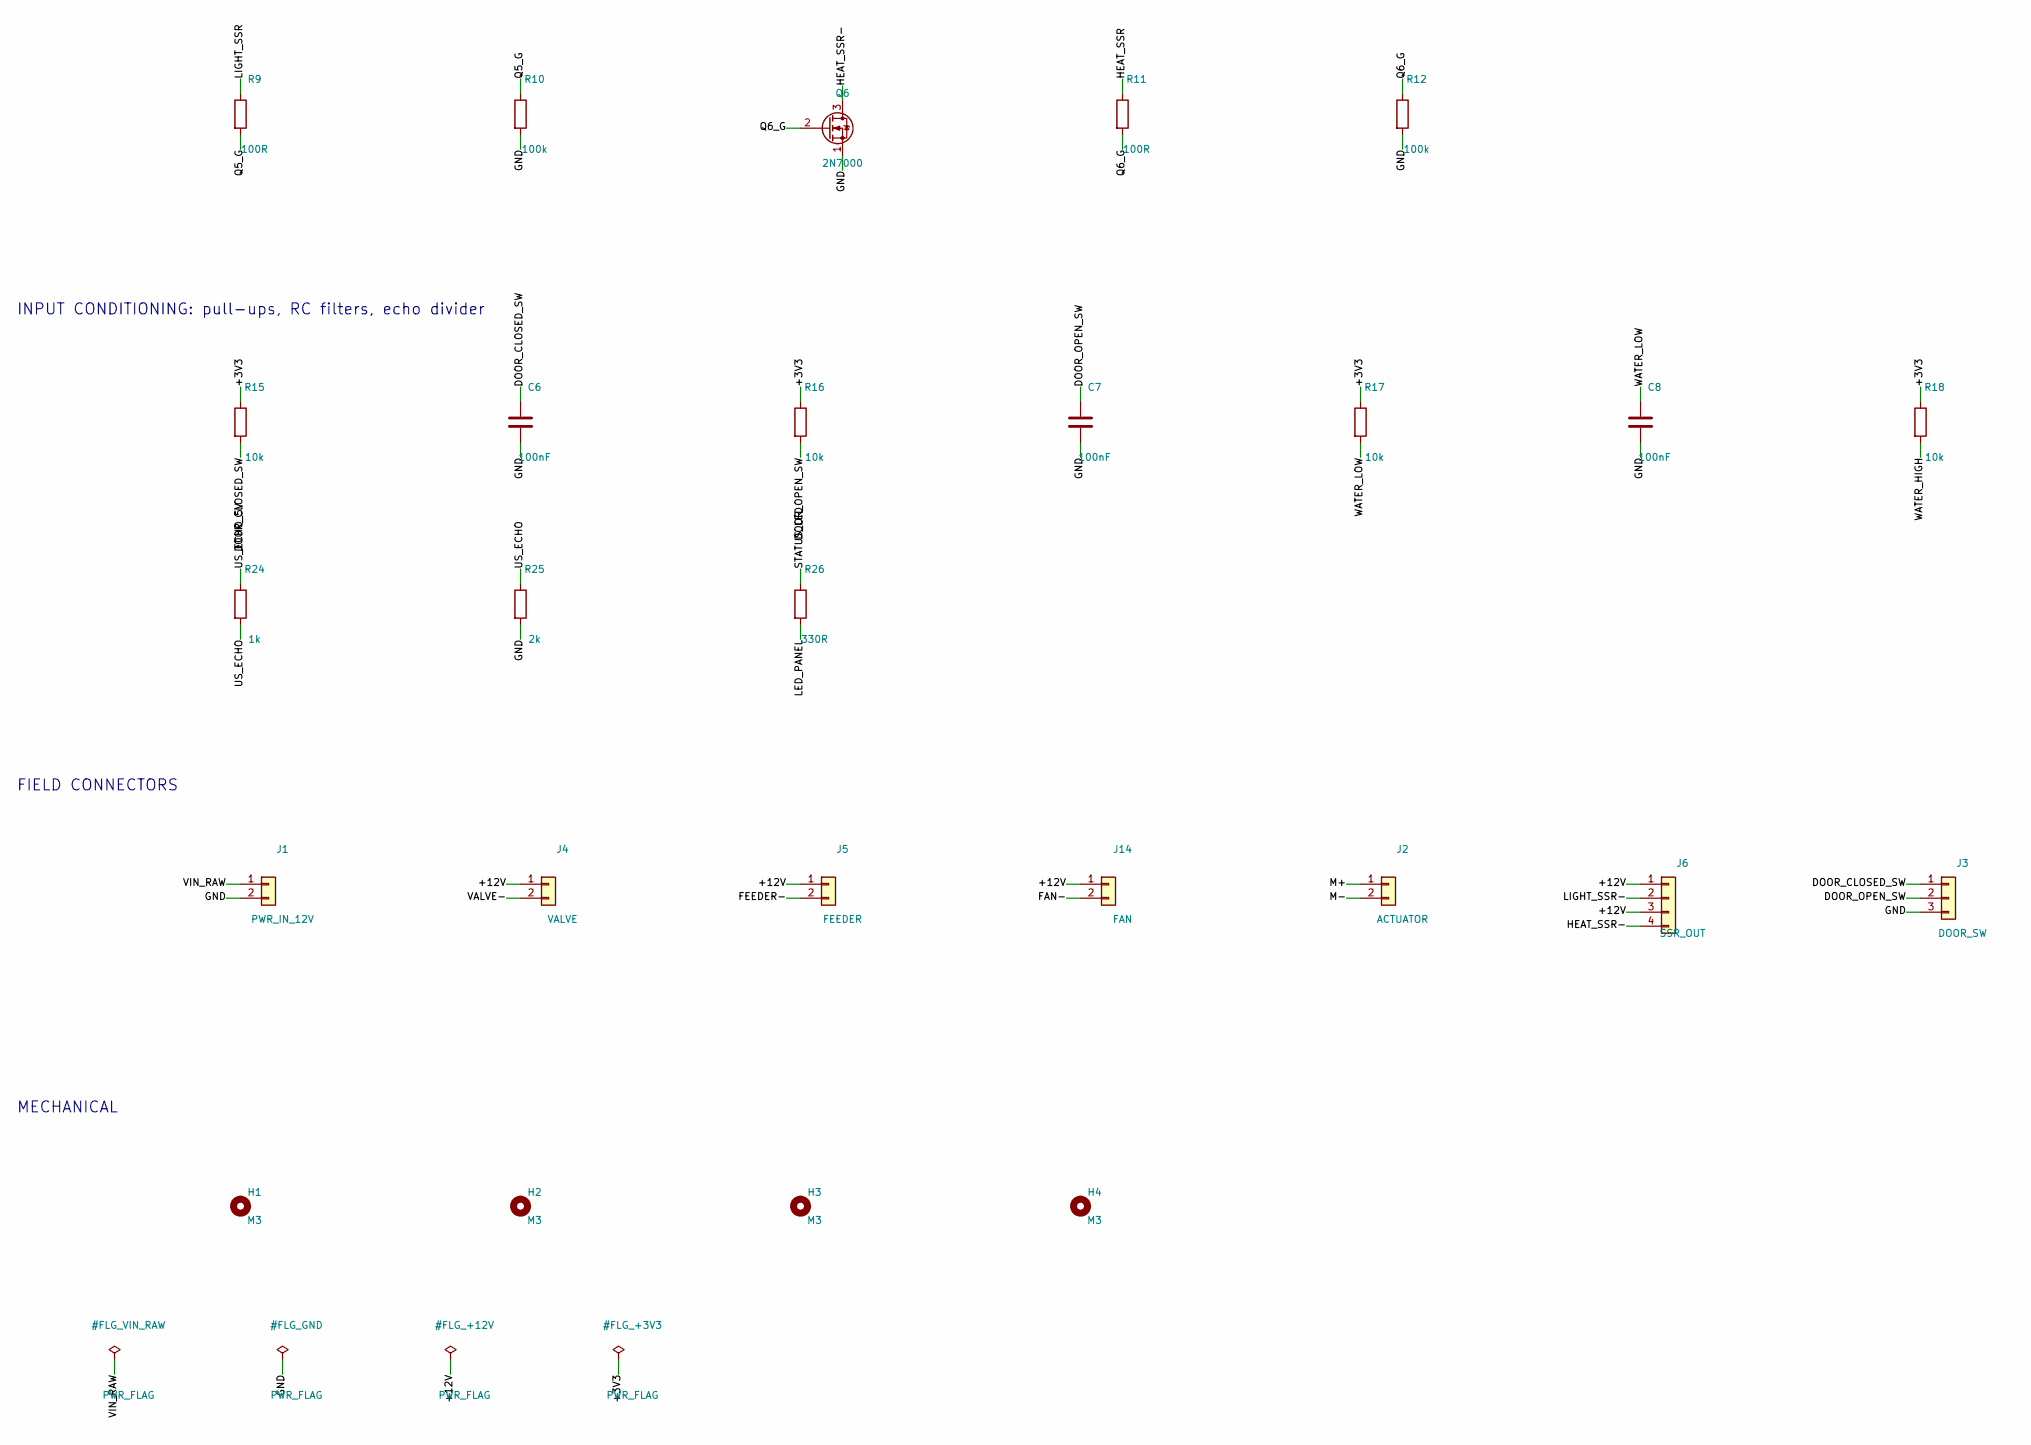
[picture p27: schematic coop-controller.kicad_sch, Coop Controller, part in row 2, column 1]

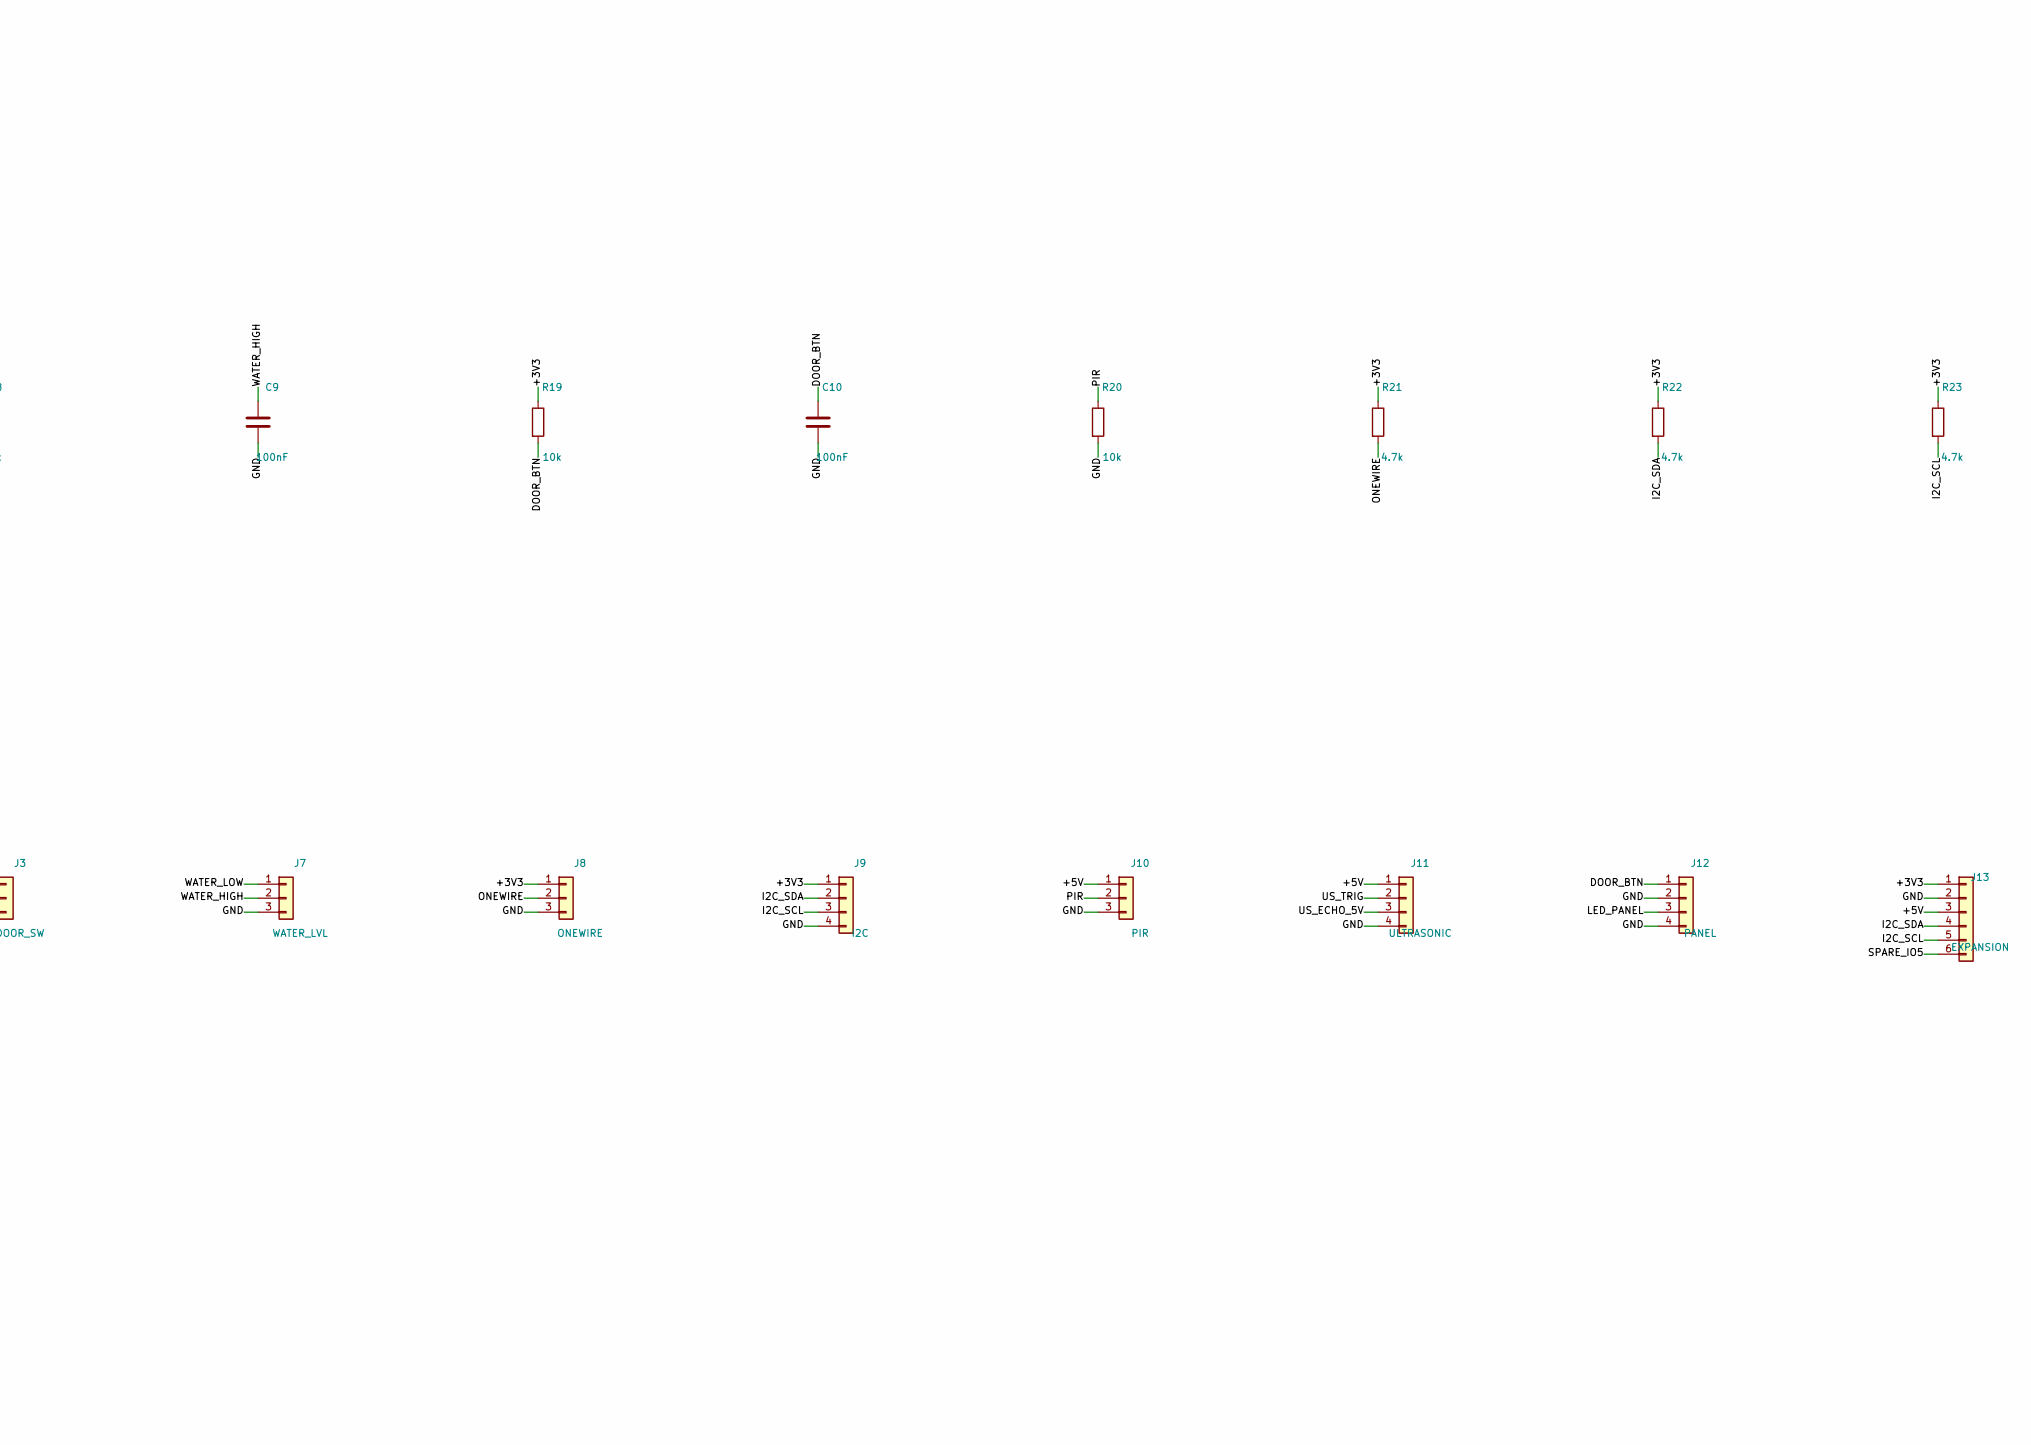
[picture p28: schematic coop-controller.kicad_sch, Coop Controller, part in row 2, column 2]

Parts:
C1: 470uF 25V; CP_Radial_D10.0mm_P5.00mm
C2: 47uF 10V; CP_Radial_D6.3mm_P2.50mm
C3, C4, C5, C6, C7, C8, C9, C10: 100nF; C_Disc_D5.0mm_W2.5mm_P5.00mm
D1: SB560; D_DO-201AD_P15.24mm_Horizontal
D2: P6KE15CA; D_DO-15_P10.16mm_Horizontal
D3, D4: 1N4148; D_DO-35_SOD27_P7.62mm_Horizontal
D5, D6, D7: 1N5822; D_DO-201AD_P15.24mm_Horizontal
D9: PWR green; LED_D3.0mm
F1: 5A slow-blow 5x20; Fuseholder_Cylinder-5x20mm_Schurter_0031_8201_Horizontal_Op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
H1, H2, H3, H4: M3; MountingHole_3.2mm_M3
J1: PWR_IN_12V; TerminalBlock_Phoenix_MKDS-1,5-2-5.08_1x02_P5.08mm_Horizont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
J2: ACTUATOR; TerminalBlock_Phoenix_MKDS-1,5-2-5.08_1x02_P5.08mm_Horizont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
J3: DOOR_SW; TerminalBlock_Phoenix_MKDS-1,5-3-5.08_1x03_P5.08mm_Horizont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
J4: VALVE; TerminalBlock_Phoenix_MKDS-1,5-2-5.08_1x02_P5.08mm_Horizont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
J5: FEEDER; TerminalBlock_Phoenix_MKDS-1,5-2-5.08_1x02_P5.08mm_Horizont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
J6: SSR_OUT; TerminalBlock_Phoenix_MKDS-1,5-4-5.08_1x04_P5.08mm_Horizont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
J7: WATER_LVL; TerminalBlock_Phoenix_MKDS-1,5-3-5.08_1x03_P5.08mm_Horizont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
J8: ONEWIRE; TerminalBlock_Phoenix_MKDS-1,5-3-5.08_1x03_P5.08mm_Horizont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
J9: I2C; TerminalBlock_Phoenix_MKDS-1,5-4-5.08_1x04_P5.08mm_Horizont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
J10: PIR; TerminalBlock_Phoenix_MKDS-1,5-3-5.08_1x03_P5.08mm_Horizont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
J11: ULTRASONIC; TerminalBlock_Phoenix_MKDS-1,5-4-5.08_1x04_P5.08mm_Horizont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
J12: PANEL; TerminalBlock_Phoenix_MKDS-1,5-4-5.08_1x04_P5.08mm_Horizont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
J13: EXPANSION; PinHeader_1x06_P2.54mm_Vertical
J14: FAN; TerminalBlock_Phoenix_MKDS-1,5-2-5.08_1x02_P5.08mm_Horizont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
J20: ESP32_DEVKITC_LEFT; PinSocket_1x19_P2.54mm_Vertical
J21: ESP32_DEVKITC_RIGHT_25.4mm; PinSocket_1x19_P2.54mm_Vertical
J22: ESP32_DEVKITC_RIGHT_22.86mm; PinSocket_1x19_P2.54mm_Vertical
K1, K2: SRD-12VDC-SL-C; Relay_SPDT_SANYOU_SRD_Series_Form_C
Q1, Q2, Q5, Q6: 2N7000; TO-92_Inline_Wide
Q3, Q4, Q7: IRLZ44N; TO-220-3_Vertical
R1, R3, R5, R7, R9, R11, R13: 100R; R_Axial_DIN0207_L6.3mm_D2.5mm_P10.16mm_Horizontal
R2, R4, R6, R8, R10, R12, R14, R31: 100k; R_Axial_DIN0207_L6.3mm_D2.5mm_P10.16mm_Horizontal
R15, R16, R17, R18, R19, R20: 10k; R_Axial_DIN0207_L6.3mm_D2.5mm_P10.16mm_Horizontal
R21, R22, R23: 4.7k; R_Axial_DIN0207_L6.3mm_D2.5mm_P10.16mm_Horizontal
R24, R30: 1k; R_Axial_DIN0207_L6.3mm_D2.5mm_P10.16mm_Horizontal
R25: 2k; R_Axial_DIN0207_L6.3mm_D2.5mm_P10.16mm_Horizontal
R26: 330R; R_Axial_DIN0207_L6.3mm_D2.5mm_P10.16mm_Horizontal
R32: 22k; R_Axial_DIN0207_L6.3mm_D2.5mm_P10.16mm_Horizontal
U1: R-78E5.0-1.0; Converter_DCDC_RECOM_R-78E-0.5_THT

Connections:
+3V3: J8.1, J9.1, J13.1, J20.1, R15.1, R16.1, R17.1, R18.1, R19.1, R21.1, R22.1, R23.1
+5V: C2.1, C4.1, J10.1, J11.1, J13.3, J20.19, R30.1, U1.3 (OUT)
+12V: C1.1, C3.1, D1.1 (K), D2.1 (A1), D3.1 (K), D4.1 (K), D5.1 (K), D6.1 (K), D7.1 (K), J4.1, J5.1, J6.1, J6.3, J14.1, K1.3, K1.5, K2.3, K2.5, R31.1, U1.1 (IN)
DOOR_BTN: C10.1, J12.1, J21.2, J22.2, R19.2
DOOR_CLOSED_SW: C6.1, J3.1, J20.7, R15.2
DOOR_CLOSE_RLY: J20.10, R3.1
DOOR_OPEN_RLY: J20.9, R1.1
DOOR_OPEN_SW: C7.1, J3.2, J20.8, R16.2
FAN-: D7.2 (A), J14.2, Q7.2 (D)
FAN_DRV: J20.12, R13.1
FEEDER-: D6.2 (A), J5.2, Q4.2 (D)
FEEDER_DRV: J20.15, R7.1
GND: C1.2, C2.2, C3.2, C4.2, C5.2, C6.2, C7.2, C8.2, C9.2, C10.2, D2.2 (A2), D9.1 (K), J1.2, J3.3, J7.3, J8.3, J9.4, J10.3, J11.4, J12.2, J12.4, J13.2, J20.14, J21.1, J21.7, J22.1, J22.7, K1.4, K2.4, Q1.1 (S), Q2.1 (S), Q3.3 (S), Q4.3 (S), Q5.1 (S), Q6.1 (S), Q7.3 (S), R2.2, R4.2, R6.2, R8.2, R10.2, R12.2, R14.2, R20.2, R25.2, R32.2, U1.2 (GND)
HEAT_SSR: J21.11, J22.11, R11.1
HEAT_SSR-: J6.4, Q6.3 (D)
I2C_SCL: J9.3, J13.5, J21.3, J22.3, R23.2
I2C_SDA: J9.2, J13.4, J21.6, J22.6, R22.2
K1_COIL: D3.2 (A), K1.2, Q1.3 (D)
K2_COIL: D4.2 (A), K2.2, Q2.3 (D)
LED_PANEL: J12.3, R26.2
LED_PWR_A: D9.2 (A), R30.2
LIGHT_SSR: J21.12, J22.12, R9.1
LIGHT_SSR-: J6.2, Q5.3 (D)
M+: J2.1, K1.1
M-: J2.2, K2.1
ONEWIRE: J8.2, J21.13, J22.13, R21.2
PIR: J10.2, J20.4, R20.1
Q1_G: Q1.2 (G), R1.2, R2.1
Q2_G: Q2.2 (G), R3.2, R4.1
Q3_G: Q3.1 (G), R5.2, R6.1
Q4_G: Q4.1 (G), R7.2, R8.1
Q5_G: Q5.2 (G), R9.2, R10.1
Q6_G: Q6.2 (G), R11.2, R12.1
Q7_G: Q7.1 (G), R13.2, R14.1
SPARE_IO5: J13.6, J21.10, J22.10
STATUS_LED: J21.15, J22.15, R26.1
US_ECHO: J21.8, J22.8, R24.2, R25.1
US_ECHO_5V: J11.3, R24.1
US_TRIG: J11.2, J21.9, J22.9
VALVE-: D5.2 (A), J4.2, Q3.2 (D)
VALVE_DRV: J20.11, R5.1
VIN_FUSED: D1.2 (A), F1.2
VIN_RAW: F1.1, J1.1
VIN_SENSE: C5.1, J20.3, R31.2, R32.1
WATER_HIGH: C9.1, J7.2, J20.6, R18.2
WATER_LOW: C8.1, J7.1, J20.5, R17.2

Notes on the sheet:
POWER INPUT: 12 V in, fuse, reverse polarity, TVS, 5 V regulator, VIN sense
ESP32-DevKitC-32E SOCKETS (fit J21 OR J22)
POP DOOR ACTUATOR: 2-relay H-bridge (K1 open / K2 close)
12 V LOW-SIDE OUTPUTS: valve, feeder, fan, SSR drivers
INPUT CONDITIONING: pull-ups, RC filters, echo divider
FIELD CONNECTORS
MECHANICAL

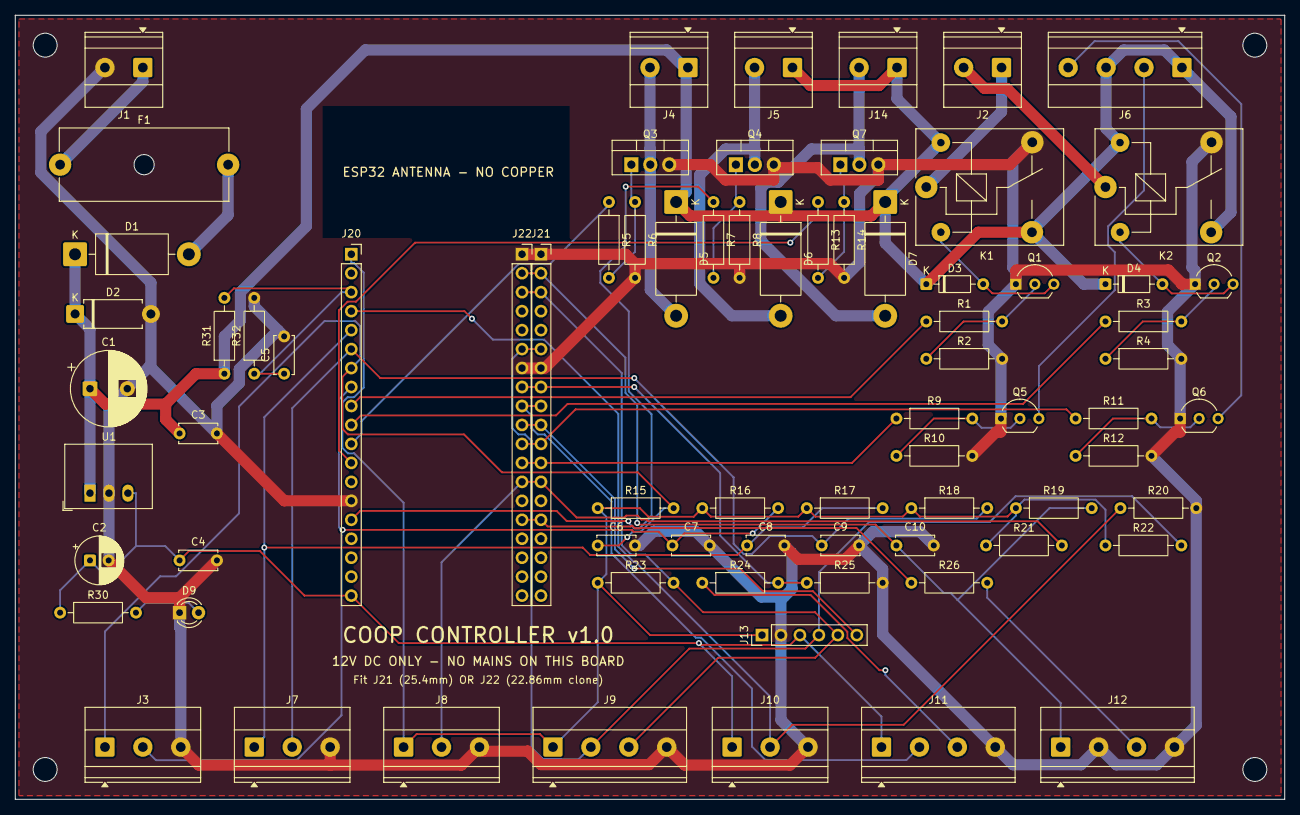
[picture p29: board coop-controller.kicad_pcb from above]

Board: 2 copper layers, 170.0 x 105.0 mm, 79 parts (0 on the bottom side), 46 nets.

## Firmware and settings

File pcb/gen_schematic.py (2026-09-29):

"""Generate coop-controller.kicad_sch from design.py.

Connectivity is made with net labels on short wire stubs at every pin, so the
schematic is a faithful, ERC-checkable netlist view of design.py. Symbols are
grouped by function on the sheet.
"""
import os
import uuid

import sexpr
from sexpr import Sym as S
import design

KICAD_SHARE = os.environ.get(
    'KICAD_SHARE', r'C:\Users\apaig\AppData\Local\Programs\KiCad\10.0\share\kicad')
PROJECT = 'coop-controller'
NS = uuid.UUID('6f1c1a52-6a8e-4a52-9b7e-1c0c0a000001')


def uid(*parts):
    """Deterministic UUIDs so regenerating doesn't churn the files."""
    return str(uuid.uuid5(NS, '/'.join(str(p) for p in parts)))


_lib_cache = {}


def load_symbol(lib_id):
    lib, name = lib_id.split(':')
    if lib not in _lib_cache:
        path = os.path.join(KICAD_SHARE, 'symbols', lib + '.kicad_sym')
        with open(path, encoding='utf-8') as f:
            tree = sexpr.parse(f.read())
        _lib_cache[lib] = {s[1]: s for s in sexpr.find(tree, 'symbol')}
    syms = _lib_cache[lib]
    sym = syms[name]
    ext = sexpr.find1(sym, 'extends')
    if ext is None:
        flat = [x for x in sym]
    else:
        parent = load_symbol(f'{lib}:{ext[1]}')
        props = {p[1]: p for p in sexpr.find(sym, 'property')}
        flat = [S('symbol'), name]
        for x in parent[2:]:
            if isinstance(x, list) and x[0] == 'property' and x[1] in props:
                flat.append(props[x[1]])
            elif isinstance(x, list) and x[0] == 'symbol':
                sub = list(x)
                sub[1] = sub[1].replace(parent[1] if isinstance(parent[1], str) else ext[1], name, 1)
                flat.append(sub)
            else:
                flat.append(x)
    return flat


def embedded(lib_id):
    sym = [x for x in load_symbol(lib_id)]
    sym[1] = lib_id
    return sym


def sym_pins(lib_id):
    """[(number, name, x, y, angle)] in symbol (y-up) coordinates."""
    out = []
    for u in sexpr.find(load_symbol(lib_id), 'symbol'):
        for p in sexpr.find(u, 'pin'):
            at = sexpr.find1(p, 'at')
            out.append((sexpr.find1(p, 'number')[1], sexpr.find1(p, 'name')[1],
                        float(at[1]), float(at[2]), int(float(at[3]))))
    return out


def effects(hide=False, justify=None):
    e = [S('effects'), [S('font'), [S('size'), 1.27, 1.27]]]
    if justify:
        e.append([S('justify'), S(justify)])
    if hide:
        e.append([S('hide'), S('yes')])
    return e


def prop(name, value, x, y, hide=False):
    return [S('property'), name, value, [S('at'), x, y, 0], effects(hide)]


def snap(v, g=1.27):
    return round(round(v / g) * g, 4)


class Sheet:
    def __init__(self):
        self.items = []
        self.lib_ids = []
        self.root = uid('root')

    def add_symbol(self, ref, lib_id, value, footprint, x, y, pin_nets, in_bom=True):
        if lib_id not in self.lib_ids:
            self.lib_ids.append(lib_id)
        pins = sym_pins(lib_id)
        s = [S('symbol'), [S('lib_id'), lib_id], [S('at'), x, y, 0], [S('unit'), 1],
             [S('exclude_from_sim'), S('no')], [S('in_bom'), S('yes' if in_bom else 'no')],
             [S('on_board'), S('yes')], [S('dnp'), S('no')], [S('uuid'), uid('sym', ref)],
             prop('Reference', ref, x + 2.54, y - 6.35 if pins else y - 2.54),
             prop('Value', value, x + 2.54, y + 6.35 if pins else y + 2.54),
             prop('Footprint', footprint, x, y, hide=True),
             prop('Datasheet', '~', x, y, hide=True)]
        for num, *_ in pins:
            s.append([S('pin'), num, [S('uuid'), uid('pin', ref, num)]])
        s.append([S('instances'), [S('project'), PROJECT,
                                   [S('path'), '/' + self.root, [S('reference'), ref], [S('unit'), 1]]]])
        self.items.append(s)
        # Stubs + labels / no-connects
        for num, name, px, py, ang in pins:
            ex, ey = snap(x + px), snap(y - py)
            out = (ang + 180) % 360     # direction pointing away from the symbol body
            dx, dy = {0: (1, 0), 90: (0, -1), 180: (-1, 0), 270: (0, 1)}[out]
            net = pin_nets.get(num, None) if pin_nets is not None else None
            if net is None:
                self.items.append([S('no_connect'), [S('at'), ex, ey], [S('uuid'), uid('nc', ref, num)]])
                continue
            lx, ly = snap(ex + dx * 2.54), snap(ey + dy * 2.54)
            self.items.append([S('wire'), [S('pts'), [S('xy'), ex, ey], [S('xy'), lx, ly]],
                               [S('stroke'), [S('width'), 0], [S('type'), S('default')]],
                               [S('uuid'), uid('w', ref, num)]])
            self.label(net, lx, ly, out, uid('lbl', ref, num))
        return len(pins)

    def label(self, net, x, y, direction, u):
        just = {0: 'left', 180: 'right', 90: 'left', 270: 'right'}[direction]
        self.items.append([S('label'), net, [S('at'), x, y, direction],
                           [S('fields_autoplaced'), S('yes')], effects(justify=just), [S('uuid'), u]])

    def text(self, t, x, y, size=2.0):
        self.items.append([S('text'), t, [S('exclude_from_sim'), S('no')], [S('at'), x, y, 0],
                           [S('effects'), [S('font'), [S('size'), size, size]], [S('justify'), S('left')]],
                           [S('uuid'), uid('text', t[:40], x, y)]])

    def dump(self, path):
        tree = [S('kicad_sch'), [S('version'), 20250114], [S('generator'), 'coop_gen'],
                [S('generator_version'), '9.0'], [S('uuid'), self.root], [S('paper'), 'A1'],
                [S('title_block'), [S('title'), 'Coop Controller'], [S('rev'), '1.0'],
                 [S('comment'), 1, 'Generated by pcb/gen_schematic.py from pcb/design.py - do not hand-edit'],
                 [S('comment'), 2, 'Low voltage (12 V DC) only. Mains/SSRs live in a separate enclosure.']],
                [S('lib_symbols')] + [embedded(l) for l in self.lib_ids]]
        tree += self.items
        tree.append([S('sheet_instances'), [S('path'), '/', [S('page'), '1']]])
        tree.append([S('embedded_fonts'), S('no')])
        with open(path, 'w', encoding='utf-8', newline='\n') as f:
            f.write(sexpr.dumps(tree) + '\n')


GROUP_TITLES = [
    ('power', 'POWER INPUT: 12 V in, fuse, reverse polarity, TVS, 5 V regulator, VIN sense'),
    ('esp', 'ESP32-DevKitC-32E SOCKETS (fit J21 OR J22)'),
    ('door', 'POP DOOR ACTUATOR: 2-relay H-bridge (K1 open / K2 close)'),
    ('outputs', '12 V LOW-SIDE OUTPUTS: valve, feeder, fan, SSR drivers'),
    ('inputs', 'INPUT CONDITIONING: pull-ups, RC filters, echo divider'),
    ('conn', 'FIELD CONNECTORS'),
    ('mech', 'MECHANICAL'),
]


def main(out):
    sh = Sheet()
    y = 25.4
    for group, title in GROUP_TITLES:
        parts = [p for p in design.PARTS if p['group'] == group]
        sh.text(title, 20.32, y)
        y += 12.7
        x = 38.1
        row_h = 0.0
        for p in parts:
            pins = sym_pins(p['lib_id'])
            ys = [-pp[3] for pp in pins] or [0]
            xs = [pp[2] for pp in pins] or [0]
            h = max(ys) - min(ys) + 12.7
            w = max(xs) - min(xs) + 50.8
            if x + w > 800:
                x = 38.1
                y += row_h + 12.7
                row_h = 0
            sx, sy = snap(x - min(xs) + 22.86, 2.54), snap(y - min(ys) + 5.08, 2.54)
            sh.add_symbol(p['ref'], p['lib_id'], p['value'], p['footprint'], sx, sy, p['pins'])
            x += w
            row_h = max(row_h, h)
        y += row_h + 20.32
    fx = 38.1
    for net in design.PWR_FLAG_NETS:
        sh.add_symbol(f'#FLG_{net}', 'power:PWR_FLAG', 'PWR_FLAG', '', snap(fx, 2.54), snap(y, 2.54),
                      {'1': net}, in_bom=False)
        fx += 30.48
    sh.dump(out)


if __name__ == '__main__':
    import sys
    main(sys.argv[1] if len(sys.argv) > 1 else 'coop-controller.kicad_sch')

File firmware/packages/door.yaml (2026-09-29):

# Automatic pop door: 12 V linear actuator driven by relays K1/K2 (2-relay H-bridge).
#
# Schedule (runs on-device, no HA needed):
#   OPEN  when sun elevation >= "Door Open Sun Elevation" AND local time >= "Door Earliest Open"
#   CLOSE when sun elevation <= "Door Close Sun Elevation" (default -6 deg = civil dusk,
#         roughly 25-35 min after sunset, by which time the flock has gone in to roost)
# If the clock isn't valid (power cut + no WiFi), it falls back to the BH1750 light level
# (10 minutes above/below the thresholds).
# The scheduler only acts when the desired state CHANGES, so a manual open/close (panel
# button, HA or web UI) holds until the next scheduled transition.
#
# End stops: the actuator's internal limit switches are primary. Reed switches report
# position and end the move. max_duration is the last-resort timeout.

globals:
  - id: door_last_desired
    type: int
    initial_value: "-1"   # -1 unknown, 0 closed, 1 open
  - id: lux_bright_minutes
    type: int
    initial_value: "0"
  - id: lux_dark_minutes
    type: int
    initial_value: "0"

switch:
  - platform: gpio
    id: door_open_relay
    pin: GPIO25   # DOOR_OPEN_RLY -> K1
    internal: true
    restore_mode: ALWAYS_OFF
    interlock: [door_close_relay]
    interlock_wait_time: 300ms
  - platform: gpio
    id: door_close_relay
    pin: GPIO26   # DOOR_CLOSE_RLY -> K2
    internal: true
    restore_mode: ALWAYS_OFF
    interlock: [door_open_relay]
    interlock_wait_time: 300ms
  - platform: template
    id: door_auto
    name: "Door Auto Mode"
    icon: mdi:calendar-clock
    optimistic: true
    restore_mode: RESTORE_DEFAULT_ON

binary_sensor:
  - platform: gpio
    id: door_closed_sensor
    name: "Door Closed Switch"
    pin:
      number: GPIO32   # DOOR_CLOSED_SW
      mode: INPUT_PULLUP
      inverted: true
    filters:
      - delayed_on_off: 50ms
  - platform: gpio
    id: door_open_sensor
    name: "Door Open Switch"
    pin:
      number: GPIO33   # DOOR_OPEN_SW
      mode: INPUT_PULLUP
      inverted: true
    filters:
      - delayed_on_off: 50ms
  - platform: gpio
    id: door_button
    name: "Door Panel Button"
    pin:
      number: GPIO23   # DOOR_BTN
      mode: INPUT_PULLUP
      inverted: true
    filters:
      - delayed_on: 50ms
    on_press:
      - cover.toggle: coop_door
  - platform: template
    name: "Door Fault"
    device_class: problem
    # Stopped with neither end switch made: jammed, obstructed or a failed reed.
    lambda: |-
      return id(coop_door).current_operation == COVER_OPERATION_IDLE &&
             !id(door_closed_sensor).state && !id(door_open_sensor).state;
    filters:
      - delayed_on: 60s
  - platform: template
    name: "Door Open After Dark"
    device_class: safety
    lambda: |-
      return id(sun_pos).elevation() < id(door_close_elev).state - 2.0 &&
             !id(door_closed_sensor).state;
    filters:
      - delayed_on: 30min

cover:
  - platform: endstop
    id: coop_door
    name: "Pop Door"
    device_class: door
    open_action:
      - switch.turn_on: door_open_relay
    open_duration: 25s
    open_endstop: door_open_sensor
    close_action:
      - switch.turn_on: door_close_relay
    close_duration: 25s
    close_endstop: door_closed_sensor
    stop_action:
      - switch.turn_off: door_open_relay
      - switch.turn_off: door_close_relay
    max_duration: 35s

number:
  - platform: template
    id: door_open_elev
    name: "Door Open Sun Elevation"
    icon: mdi:weather-sunset-up
    entity_category: config
    optimistic: true
    restore_value: true
    initial_value: 2
    min_value: -6
    max_value: 15
    step: 0.5
    unit_of_measurement: "°"
  - platform: template
    id: door_close_elev
    name: "Door Close Sun Elevation"
    icon: mdi:weather-sunset-down
    entity_category: config
    optimistic: true
    restore_value: true
    initial_value: -6
    min_value: -12
    max_value: 0
    step: 0.5
    unit_of_measurement: "°"
  - platform: template
    id: door_earliest_open
    name: "Door Earliest Open"
    icon: mdi:clock-start
    entity_category: config
    optimistic: true
    restore_value: true
    initial_value: 6.5
    min_value: 4
    max_value: 10
    step: 0.25
    unit_of_measurement: "h"
  - platform: template
    id: door_lux_open
    name: "Door Fallback Open Lux"
    entity_category: config
    optimistic: true
    restore_value: true
    initial_value: 100
    min_value: 5
    max_value: 2000
    step: 5
    unit_of_measurement: "lx"
  - platform: template
    id: door_lux_close
    name: "Door Fallback Close Lux"
    entity_category: config
    optimistic: true
    restore_value: true
    initial_value: 3
    min_value: 0
    max_value: 100
    step: 1
    unit_of_measurement: "lx"
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

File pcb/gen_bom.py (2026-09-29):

"""Grouped PCB bill of materials from design.py (CSV)."""
import csv
import sys
from collections import OrderedDict

import design


def natural(ref):
    head = ref.rstrip('0123456789')
    return head, int(ref[len(head):] or 0)


def main(out):
    groups = OrderedDict()
    for p in sorted(design.PARTS, key=lambda p: natural(p['ref'])):
        if p['group'] == 'mech':
            continue
        key = (p['value'], p['footprint'])
        g = groups.setdefault(key, {'refs': [], 'note': p['note'], 'lib': p['lib_id']})
        g['refs'].append(p['ref'])
    with open(out, 'w', newline='', encoding='utf-8') as f:
        w = csv.writer(f)
        w.writerow(['Qty', 'References', 'Value', 'Footprint', 'Notes'])
        for (value, fp), g in groups.items():
            w.writerow([len(g['refs']), ' '.join(g['refs']), value, fp.split(':')[1], g['note']])
    print(f'{sum(len(g["refs"]) for g in groups.values())} parts in {len(groups)} lines -> {out}')


if __name__ == '__main__':
    main(sys.argv[1] if len(sys.argv) > 1 else 'bom.csv')

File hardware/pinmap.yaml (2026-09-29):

# Single source of truth for controller GPIO + connector assignments.
# Consumed by: tools/check_consistency.py, pcb/generate.py, docs.
# Board: ESP32-DevKitC-32E (38-pin). Change here first, then regenerate/check.

board: esp32dev
pins:
  - {gpio: 21, signal: I2C_SDA,        dir: io,  connector: J9}
  - {gpio: 22, signal: I2C_SCL,        dir: out, connector: J9}
  - {gpio: 4,  signal: ONEWIRE,        dir: io,  connector: J8}
  - {gpio: 25, signal: DOOR_OPEN_RLY,  dir: out, connector: J2}
  - {gpio: 26, signal: DOOR_CLOSE_RLY, dir: out, connector: J2}
  - {gpio: 32, signal: DOOR_CLOSED_SW, dir: in,  connector: J3}
  - {gpio: 33, signal: DOOR_OPEN_SW,   dir: in,  connector: J3}
  - {gpio: 27, signal: VALVE_DRV,      dir: out, connector: J4}
  - {gpio: 13, signal: FEEDER_DRV,     dir: out, connector: J5}
  - {gpio: 14, signal: FAN_DRV,        dir: out, connector: J14}
  - {gpio: 16, signal: LIGHT_SSR,      dir: out, connector: J6}
  - {gpio: 17, signal: HEAT_SSR,       dir: out, connector: J6}
  - {gpio: 34, signal: WATER_LOW,      dir: in,  connector: J7}
  - {gpio: 35, signal: WATER_HIGH,     dir: in,  connector: J7}
  - {gpio: 39, signal: PIR,            dir: in,  connector: J10}
  - {gpio: 18, signal: US_TRIG,        dir: out, connector: J11}
  - {gpio: 19, signal: US_ECHO,        dir: in,  connector: J11}
  - {gpio: 23, signal: DOOR_BTN,       dir: in,  connector: J12}
  - {gpio: 2,  signal: STATUS_LED,     dir: out, connector: J12}
  - {gpio: 36, signal: VIN_SENSE,      dir: adc, connector: null}
  - {gpio: 5,  signal: SPARE_IO5,      dir: io,  connector: J13}

connectors:
  J1:  {name: PWR_IN,     pins: ["VIN_RAW", "GND"]}   # VIN_RAW = +12 V in, before fuse/diode
  J2:  {name: ACTUATOR,   pins: ["M+", "M-"]}
  J3:  {name: DOOR_SW,    pins: ["DOOR_CLOSED_SW", "DOOR_OPEN_SW", "GND"]}
  J4:  {name: VALVE,      pins: ["+12V", "VALVE-"]}
  J5:  {name: FEEDER,     pins: ["+12V", "FEEDER-"]}
  J6:  {name: SSR_OUT,    pins: ["+12V", "LIGHT_SSR-", "+12V", "HEAT_SSR-"]}
  J7:  {name: WATER_LVL,  pins: ["WATER_LOW", "WATER_HIGH", "GND"]}
  J8:  {name: ONEWIRE,    pins: ["+3V3", "ONEWIRE", "GND"]}
  J9:  {name: I2C,        pins: ["+3V3", "I2C_SDA", "I2C_SCL", "GND"]}
  J10: {name: PIR,        pins: ["+5V", "PIR", "GND"]}
  J11: {name: ULTRASONIC, pins: ["+5V", "US_TRIG", "US_ECHO_5V", "GND"]}
  J12: {name: PANEL,      pins: ["DOOR_BTN", "GND", "LED_PANEL", "GND"]}
  J13: {name: EXPANSION,  pins: ["+3V3", "GND", "+5V", "I2C_SDA", "I2C_SCL", "SPARE_IO5"]}
  J14: {name: FAN,        pins: ["+12V", "FAN-"]}

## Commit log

2026-09-29 Add project spec, pin map and ESPHome firmware
    Spec covers the 50-bird coop architecture, tiered subsystems, power
    architecture, safety notes and a single-source GPIO map.
    Firmware (ESPHome 2026.9, esp-idf): on-device door scheduling with
    sun-elevation + lux fallback, water fill with lockout, de-icer
    thermostat, feeder auger, winter lighting, fan, PIR, BLE proxy.
    Verified: esphome config (both nodes) and full compile of the
    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
    [coop-controller.yaml]
2026-09-29 Add generated KiCad controller PCB and consistency checker
    pcb/design.py is the single circuit source; generators emit the
    schematic (labels per pin), placed board, Freerouting autoroute,
    ground pours, Gerbers/drill, schematic PDF and grouped BOM.
    Verified: ERC 0 violations; DRC 0 errors, 0 unconnected, 0
    schematic-parity issues; tools/check_consistency.py passes (pin map
    vs firmware vs PCB sockets/connectors vs spec vs schematic netlist).
    [bom.csv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]
2026-09-29 Add OpenSCAD 3D-printed parts with STL renders
    Feeder funnel adapter, ESP32-CAM hood/bracket, PIR housing, BLE
    thermometer case, BME280 radiation shield, reed switch/magnet
    brackets, ultrasonic hopper-lid gland, PCB back-plate.
    Verified: render.sh renders all 15 STLs with no OpenSCAD errors or
    empty meshes (OpenSCAD 2021.01).
    [ble_case_base.stl, ble_case_lid.stl, ble_sensor_case.scad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]
2026-09-29 Add coop construction plan, wiring/plumbing/run docs and diagrams
    10x20 ft 4/12-gable coop on skids: build sequence, cut list, 12-box
    exterior nest bay, 5x9 ft roosts over a poop board, actuator pop door,
    ventilation. Wiring doc separates the electrician-installed 120 V
    mains box from the 12 V controller and lists every terminal. Plumbing
    covers backflow, regulation, fail-closed fill and winterising. Run
    and rotational electric-netting paddocks for free-ranging.
    Design fixes found during takeoff: roosts resized to fit the 9'-5"
    interior, nest boxes moved to one row below roost height, actuator
    stroke 18", PSU upsized to HDR-100-12N, and the feeder now waits for
    the door so the auger and act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
2026-09-29 Add priced parts list and Home Assistant integration docs
    docs/parts.csv is the priced BOM (2026 USD estimates) for Tier 1
    (coop, run, range, power), Tier 2 (automation) and optional add-ons;
    tools/gen_parts_list.py renders docs/parts-list.md with category and
    tier totals and a --check mode. HA docs cover flashing, adoption, the
    entity reference, alert automations and a ready-made dashboard.
    The consistency checker now also verifies that every HA entity ID in
    the docs is produced by the firmware. Corrected the PSU rating to
    7.5 A (HDR-100-12N datasheet).
    Verified: parts list --check clean; HA YAML parses and passes
    yamllint; consistency check passes, and injected errors make it fail.
    Co-A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
    [parts.csv]
2026-09-30 Add illustrative OpenSCAD coop model and renders
    construction/model/coop_model.scad models the coop, run, nest bay,
    pop door, interior (roosts, poop board, trough, nipple line) and the
    new exterior feed/water service station; render.sh produces six views
    in construction/renders/.
    Verified: all six views render without OpenSCAD warnings and were
    visually checked.
    [coop_model.scad]
2026-09-30 Service feed and water from outside; apply cost-saving measures
    Feed and water move to an exterior service station on the east wall:
    a ~350 lb sloped-floor gravity bin feeds an indoor trough through a
    wall slot, and the 30 gal drum plus all pressurised plumbing sit in
    the station with only a gravity line entering the coop. The motorized
    auger becomes an optional add-on (firmware schedule now defaults off;
    level sensor retargeted to the bin lid).
    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
    [coop-controller.yaml, parts.csv]
